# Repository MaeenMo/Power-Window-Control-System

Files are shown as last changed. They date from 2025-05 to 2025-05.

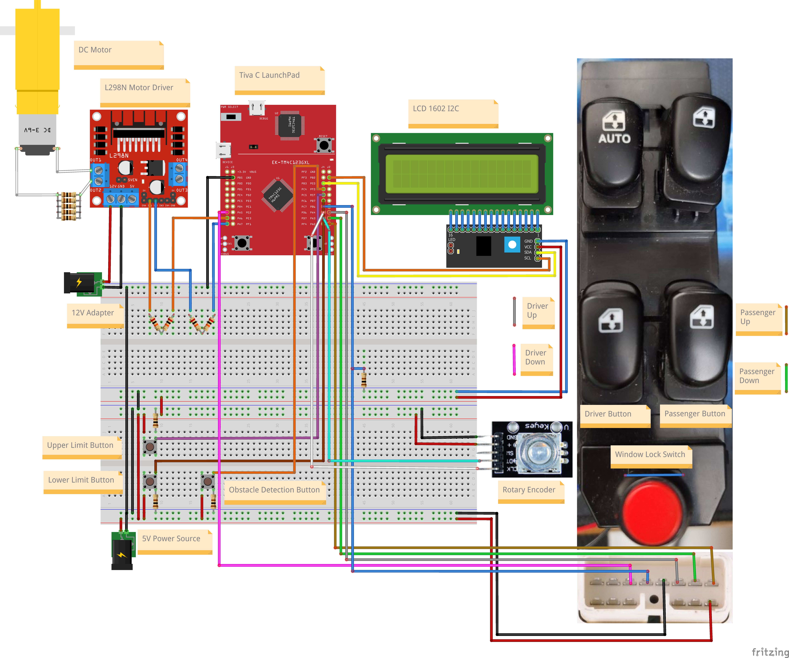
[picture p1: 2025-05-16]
Fritzing/Circuit Diagram.png

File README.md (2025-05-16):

# Power Window Control System

A real-time embedded system for controlling automotive power windows using the **TM4C123GH6PM** microcontroller and **FreeRTOS**.

---

## 🚗 Features

- **Dual Control:** Driver and passenger can operate the window independently.
- **Manual and Auto Modes:**
    - *Manual:* Window moves while the button is held.
    - *Auto:* One-touch open/close.
- **Safety Mechanisms:**
    - *Anti-pinch protection:* Automatically reverses window if obstacle is detected.
    - *Window lock:* Driver can disable passenger controls.
    - *Limit switch detection:* Prevents over-travel at top/bottom ends.
- **Encoder-Based Tracking:**
    - Real-time position tracking via rotary encoder.
    - Accurate calculation of open/close percentage.
- **User Feedback:**
    - LCD shows window state, lock status, and position percentage.
- **Debounced Inputs:** All switches are debounced using timers to ensure reliable signal handling.

---

## 🧰 Hardware Components

| Component | Description |
|---|---|
| TM4C123GH6PM MCU | Main controller |
| DC Motor + H-Bridge Driver | Controls window movement |
| Rotary Encoder (QEI) | Tracks window position |
| LCD (I2C) | Displays system status |
| Buttons (x4) | Driver/Passenger Up & Down |
| Limit Switches (x2) | Upper and lower travel limits |
| Lock Switch | Enables/disables passenger side |
| IR Obstacle Sensor (Simulated with a push-button) | Detects object in window path |

---

## 📍 Pin Configuration

### **Port A**
| Pin | Function |
|-----|---|
| PA2 | Passenger Up Button |
| PA3 | Passenger Down Button |
| PA4 | Driver Up Button |
| PA5 | Driver Down Button |
| PA6 | Motor IN1 (transistor base) |
| PA7 | Motor IN2 (transistor base) |

### **Port B**
| Pin | Function |
|-----|---|
| PB2 | I2C SCL |
| PB3 | I2C SDA |

### **Port C**
| Pin | Function |
|-----|---|
| PC4 | Object Detection Sensor |
| PC5 | Upper Limit Switch |
| PC6 | Lower Limit Switch |
| PC7 | Window Lock Switch |

### **Port D**
| Pin | Function |
|-----|---|
| PD6 | QEI Phase A |
| PD7 | QEI Phase B |

---

## 🧠 Software Architecture

### 🔧 Modules

- **Window Control Module:** Handles manual and auto control from driver and passenger sides.
- **Sensor & Safety Module:** Processes limit switches, lock switch, and obstacle detection.
- **Encoder Module:** Computes window position using rotary encoder and maps it to a 0–100% range.
- **LCD Module:** Displays real-time status (window state, lock icon, percentage open).
- **Configuration Module:** Initializes ports, system clock, and defines macros and pin assignments.

### 🧵 Tasks (FreeRTOS)

- `vDriverWindowElevateTask`
- `vDriverWindowLowerTask`
- `vPassengerWindowElevateTask`
- `vPassengerWindowLowerTask`
- `vLockWindowsTask`
- `vUpperLimitTask`
- `vLowerLimitTask`
- `vObstacleDetection`
- `vEncoderMonitorTask`
- `vStatusProducerTask`
- `vLCDTask`

---

## 🛡️ Safety Features

| Feature | Description |
|---|---|
| **Anti-Pinch** | IR sensor detects obstacles and reverses motor to prevent injury |
| **Window Lock** | Driver can lock/unlock passenger control |
| **Limit Protection**| Stops motor at top and bottom window positions |
| **Auto Mode Cancel**| Any button press cancels auto movement immediately |
| **Encoder Clamping**| Window position is clamped between 0–100% to prevent invalid states |

---

## ⚙️ Build & Flash Instructions

1. Open the project in **Keil uVision5**
2. Ensure **TivaWare** and **FreeRTOS** are properly linked.
3. Connect TM4C123GH6PM via **USB Debug Interface**.
4. Build the project (`Rebuild all`).
5. Flash to board (`Load` or `Ctrl + F8`).

---

## 📦 Dependencies

- [TivaWare Peripheral Driver Library](https://www.ti.com/tool/SW-TM4C)
- [FreeRTOS Kernel](https://freertos.org/)
- Keil MDK ARM IDE (or compatible)

---

## ✅ Future Improvements

- Add QEI direction filtering to discard noise.
- Add velocity monitoring for smoother motion.
- Enable EEPROM/Flash storage to retain calibration values.

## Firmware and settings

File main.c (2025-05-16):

#include "Config.h"
#include "Helper_Functions.h"
#include "WindowTasks.h"
#include "Safety.h"
#include "RotaryEncoder.h"
#include "LCD.h"

/* Global Variables */
#pragma clang diagnostic push
#pragma ide diagnostic ignored "EndlessLoop"

volatile bool debounce_in_progress = false; // variable for handling the debounce state

TimerHandle_t xDebounceTimer;

/*––– MAIN –––*/
int main(void) {
    // Clock
    SysCtlClockSet(
            SYSCTL_SYSDIV_5 | SYSCTL_USE_PLL | SYSCTL_OSC_MAIN | SYSCTL_XTAL_16MHZ
    );

    // Init I/O
    PortA_Config();         // must set PA6, PA7 outputs; PA4..2 inputs w/ digital enable
    PortB_Config_LCD();     // LCD sets PB2-SCL, PB3-SDA
    PortC_Config();         // limit switches, lock switch, IR sensor
    PortD_Config_QEI();     // QEI inputs (Encoder) PD6-CLK PD7-DT

    // LCD
    I2CMasterInitExpClk(I2C0_BASE, SysCtlClockGet(), false);
    LCD_I2C_Init();

    // --- create queue & tasks ---
    xStatusQueue = xQueueCreate(1, sizeof(StatusMsg_t));

    // Semaphores
    xDriverUpSem       = xSemaphoreCreateBinary();
    xDriverDownSem     = xSemaphoreCreateBinary();
    xPassengerUpSem    = xSemaphoreCreateBinary();
    xPassengerDownSem  = xSemaphoreCreateBinary();
    xLockWindowsSem    = xSemaphoreCreateBinary();
    xUpperLimitSem     = xSemaphoreCreateBinary();
    xLowerLimitSem     = xSemaphoreCreateBinary();
    xObstacleDetectionSem = xSemaphoreCreateBinary();

    // GPIO interrupts
    GPIOIntRegister(GPIO_PORTA_BASE, ISRHandlers);
    GPIOIntRegister(GPIO_PORTC_BASE, ISRHandlers);

    // Create single-touch driver‑up task
    xTaskCreate(vDriverWindowElevateTask, "DrvUp", 128, NULL, 3, &xDriverWindowElevateTaskHandle);
    xTaskCreate(vDriverWindowLowerTask, "DrvDn", 128, NULL, 3, &xDriverWindowLowerTaskHandle);
    xTaskCreate(vPassengerWindowElevateTask, "PUp", 128, NULL, 3, &xPassengerWindowElevateTaskHandle);
    xTaskCreate(vPassengerWindowLowerTask, "PDn", 128, NULL, 3, &xPassengerWindowLowerTaskHandle);
    xTaskCreate(vLockWindowsTask, "LockCtrl", 128, NULL, 4, &xLockWindowsTaskHandle);
    xTaskCreate(vUpperLimitTask, "UpperLimit", 128, NULL, 5, &xUpperLimitTaskHandle);
    xTaskCreate(vLowerLimitTask, "LowerLimit", 128, NULL, 5, &xLowerLimitTaskHandle);
    xTaskCreate(vObstacleDetection, "ObstacleDet", 128, NULL, 6, &xObstacleDetectionHandle);
    xTaskCreate(vLCDTask,            "LCD",   128, NULL, 2, NULL);
    xTaskCreate(vStatusProducerTask, "Stat",  128, NULL, 1, NULL);
    xTaskCreate(vEncoderMonitorTask,       "Enc",   128, NULL, 1, NULL);

    xDebounceTimer = xTimerCreate(
            "DebounceTimer",                // Timer name
            pdMS_TO_TICKS(350),             // Timer period
            pdFALSE,                        // One-shot timer
            (void*)0,                       // Timer ID
            vDebounceTimerCallback          // Callback function
    );

    // Start scheduler
    vTaskStartScheduler();

    while (1);
    // should never get here
}

/* Idle Task for sleeping the processor */
void vApplicationIdleHook( void ) {
    // Checking for initial condition of switch
    lock_state = GPIOPinRead(Sensors_Port,Window_Lock_Switch);
    // Disabling the passenger control
    if (lock_state == LOW){
        vTaskSuspend(xPassengerWindowElevateTaskHandle);
        vTaskSuspend(xPassengerWindowLowerTaskHandle);
    }
    /* Put the microcontroller in a low power mode */
    SysCtlSleep();
}

/*––– ISR HANDLER –––*/
void ISRHandlers(void) {
    BaseType_t xHigherPriorityTaskWoken = pdFALSE;

    // Read *all* pending (masked) interrupts on each port
    uint32_t a = GPIOIntStatus(GPIO_PORTA_BASE, true);
    uint32_t c = GPIOIntStatus(GPIO_PORTC_BASE, true);

    // If it's a button bounce, and we're still debouncing, clear PORTA and PORTC.
    if( debounce_in_progress && a )
    {
        GPIOIntClear(GPIO_PORTA_BASE, a);
        GPIOIntClear(GPIO_PORTC_BASE, c);
        return;
    }

    // If this is the first button edge, start the debounce timer
    if( a )
    {
        debounce_in_progress = true;
        xTimerStartFromISR(xDebounceTimer, &xHigherPriorityTaskWoken);
    }

    // — PORT A —
    if (a & Driver_Elevate_Button) {
        if(last_task == STOP){
            // Wake the driver‑up task
            xSemaphoreGiveFromISR(xDriverUpSem, &xHigherPriorityTaskWoken);
        }
    }
    else if (a & Driver_Lower_Button) {
        if (last_task == STOP) {
            // Wake the passenger‑up task
            xSemaphoreGiveFromISR(xDriverDownSem, &xHigherPriorityTaskWoken);
        }
    }
    else if (a & Passenger_Elevate_Button) {
        if (lock_state == HIGH && last_task == STOP) {
            // Wake the passenger‑up task
            xSemaphoreGiveFromISR(xPassengerUpSem, &xHigherPriorityTaskWoken);
        }
    }
    else if (a & Passenger_Lower_Button) {
        if (lock_state == HIGH && last_task == STOP) {
            // Wake the passenger‑down task
            xSemaphoreGiveFromISR(xPassengerDownSem, &xHigherPriorityTaskWoken);
        }
    }
    // — PORT C —
    else if (c & Window_Lock_Switch) {
        GPIOIntClear(GPIO_PORTC_BASE, Window_Lock_Switch);
        xSemaphoreGiveFromISR(xLockWindowsSem, &xHigherPriorityTaskWoken);
    }
    else if (c & Window_Upper_Limit) {
        GPIOIntClear(GPIO_PORTC_BASE, Window_Upper_Limit);

        uint8_t good = 0;
        for (uint8_t i = 0; i < 3; ++i) {
            if (GPIOPinRead(Sensors_Port, Window_Upper_Limit))
                good++;
            for (uint8_t i = 0; i < 10; ++i);
        }
        if (good == 0x3) {
            xSemaphoreGiveFromISR(xUpperLimitSem, &xHigherPriorityTaskWoken);
        }

    }
    else if (c & Window_Lower_Limit) {
        GPIOIntClear(GPIO_PORTC_BASE, Window_Lower_Limit);

        uint8_t good = 0;
        for (uint8_t i = 0; i < 3; ++i) {
            if (GPIOPinRead(Sensors_Port, Window_Lower_Limit))
                good++;
            for (uint8_t i = 0; i < 10; i++);
        }
        if (good == 0x3) {
            xSemaphoreGiveFromISR(xLowerLimitSem, &xHigherPriorityTaskWoken);
        }
    }
    else if (c & Object_Detection_Sensor) {
        GPIOIntClear(GPIO_PORTC_BASE, Object_Detection_Sensor);

        if (operation == UP) {
            uint8_t good = 0;
            for (uint8_t i = 0; i < 3; ++i) {
                if (GPIOPinRead(Sensors_Port, Object_Detection_Sensor))
                    good++;
                for (uint8_t i = 0; i < 10; ++i);
            }
            if (good == 0x3) {
                xSemaphoreGiveFromISR(xObstacleDetectionSem, &xHigherPriorityTaskWoken);
            }
        }
    }
    portYIELD_FROM_ISR(xHigherPriorityTaskWoken);
}

void vDebounceTimerCallback(TimerHandle_t xTimer) {
    debounce_in_progress = false;
}

#pragma clang diagnostic pop

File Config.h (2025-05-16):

#ifndef __PORT_Configuration__
#define __PORT_Configuration__ 

#include <stdint.h>
#include <stdbool.h>
#include <stdio.h>

#include "FreeRTOS.h"
#include "task.h"
#include "queue.h"
#include "semphr.h"
#include "timers.h"

#include "inc/hw_memmap.h"
#include "inc/hw_types.h"
#include "inc/hw_ints.h"

#include "driverlib/sysctl.h"
#include "driverlib/gpio.h"
#include "driverlib/pin_map.h"
#include "driverlib/interrupt.h"
#include "driverlib/i2c.h"
#include "driverlib/qei.h"

#include "lcd_i2c.h"

#include "TM4C123GH6PM.h"
#define SYSCTL_RCGCGPIO_R       (*((volatile unsigned long *)0x400FE608))

/* PORTA Registers */
#define GPIO_PORTA_DATA_BITS_R  ((volatile uint32_t *)0x40004000)
#define GPIO_PORTA_DATA_R       (*((volatile uint32_t *)0x400043FC))
#define GPIO_PORTA_DIR_R        (*((volatile uint32_t *)0x40004400))
#define GPIO_PORTA_IS_R         (*((volatile uint32_t *)0x40004404))
#define GPIO_PORTA_IBE_R        (*((volatile uint32_t *)0x40004408))
#define GPIO_PORTA_IEV_R        (*((volatile uint32_t *)0x4000440C))
#define GPIO_PORTA_IM_R         (*((volatile uint32_t *)0x40004410))
#define GPIO_PORTA_RIS_R        (*((volatile uint32_t *)0x40004414))
#define GPIO_PORTA_MIS_R        (*((volatile uint32_t *)0x40004418))
#define GPIO_PORTA_ICR_R        (*((volatile uint32_t *)0x4000441C))
#define GPIO_PORTA_AFSEL_R      (*((volatile uint32_t *)0x40004420))
#define GPIO_PORTA_DR2R_R       (*((volatile uint32_t *)0x40004500))
#define GPIO_PORTA_DR4R_R       (*((volatile uint32_t *)0x40004504))
#define GPIO_PORTA_DR8R_R       (*((volatile uint32_t *)0x40004508))
#define GPIO_PORTA_ODR_R        (*((volatile uint32_t *)0x4000450C))
#define GPIO_PORTA_PUR_R        (*((volatile uint32_t *)0x40004510))
#define GPIO_PORTA_PDR_R        (*((volatile uint32_t *)0x40004514))
#define GPIO_PORTA_SLR_R        (*((volatile uint32_t *)0x40004518))
#define GPIO_PORTA_DEN_R        (*((volatile uint32_t *)0x4000451C))
#define GPIO_PORTA_LOCK_R       (*((volatile uint32_t *)0x40004520))
#define GPIO_PORTA_CR_R         (*((volatile uint32_t *)0x40004524))
#define GPIO_PORTA_AMSEL_R      (*((volatile uint32_t *)0x40004528))
#define GPIO_PORTA_PCTL_R       (*((volatile uint32_t *)0x4000452C))
#define GPIO_PORTA_ADCCTL_R     (*((volatile uint32_t *)0x40004530))
#define GPIO_PORTA_DMACTL_R     (*((volatile uint32_t *)0x40004534))
	
/* PORTB Registers */
#define GPIO_PORTB_DATA_BITS_R  ((volatile uint32_t *)0x40005000)
#define GPIO_PORTB_DATA_R       (*((volatile uint32_t *)0x400053FC))
#define GPIO_PORTB_DIR_R        (*((volatile uint32_t *)0x40005400))
#define GPIO_PORTB_IS_R         (*((volatile uint32_t *)0x40005404))
#define GPIO_PORTB_IBE_R        (*((volatile uint32_t *)0x40005408))
#define GPIO_PORTB_IEV_R        (*((volatile uint32_t *)0x4000540C))
#define GPIO_PORTB_IM_R         (*((volatile uint32_t *)0x40005410))
#define GPIO_PORTB_RIS_R        (*((volatile uint32_t *)0x40005414))
#define GPIO_PORTB_MIS_R        (*((volatile uint32_t *)0x40005418))
#define GPIO_PORTB_ICR_R        (*((volatile uint32_t *)0x4000541C))
#define GPIO_PORTB_AFSEL_R      (*((volatile uint32_t *)0x40005420))
#define GPIO_PORTB_DR2R_R       (*((volatile uint32_t *)0x40005500))
#define GPIO_PORTB_DR4R_R       (*((volatile uint32_t *)0x40005504))
#define GPIO_PORTB_DR8R_R       (*((volatile uint32_t *)0x40005508))
#define GPIO_PORTB_ODR_R        (*((volatile uint32_t *)0x4000550C))
#define GPIO_PORTB_PUR_R        (*((volatile uint32_t *)0x40005510))
#define GPIO_PORTB_PDR_R        (*((volatile uint32_t *)0x40005514))
#define GPIO_PORTB_SLR_R        (*((volatile uint32_t *)0x40005518))
#define GPIO_PORTB_DEN_R        (*((volatile uint32_t *)0x4000551C))
#define GPIO_PORTB_LOCK_R       (*((volatile uint32_t *)0x40005520))
#define GPIO_PORTB_CR_R         (*((volatile uint32_t *)0x40005524))
#define GPIO_PORTB_AMSEL_R      (*((volatile uint32_t *)0x40005528))
#define GPIO_PORTB_PCTL_R       (*((volatile uint32_t *)0x4000552C))
#define GPIO_PORTB_ADCCTL_R     (*((volatile uint32_t *)0x40005530))
#define GPIO_PORTB_DMACTL_R     (*((volatile uint32_t *)0x40005534))
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

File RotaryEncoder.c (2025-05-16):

#include "RotaryEncoder.h"

volatile uint32_t TOTAL_PULSES = 150UL;   // pulses from top→bottom
volatile uint32_t windowPct      = 0;        // 0–100%


/*––– ENCODER MONITOR –––*/
void vEncoderMonitorTask(void *pv) {
    QEIPositionSet(QEI0_BASE, 0);
    while (1) {
        int8_t dir = QEIDirectionGet(QEI0_BASE);  // +1 = CW, -1 = CCW

        if (operation == UP && dir > 0) {
            // Closing: percentage increases
            uint32_t speed = QEIVelocityGet(QEI0_BASE);
            if (speed < 16) {
                QEIPositionSet(QEI0_BASE, prev_pos); // ignore as noise
                continue;
            }
            handle_position_bounds(&pos);
            if (pos > prev_pos) {
                windowPct = (pos * 100UL / TOTAL_PULSES);
                prev_pos = pos;
            }
            else QEIPositionSet(QEI0_BASE, prev_pos);
            if (windowPct > 100) windowPct = 100;
            if (windowPct == 100){
                prev_pos = TOTAL_PULSES;
                trigger_limit_semaphore(xUpperLimitSem, &encoder_limit);
            }
        } else if (operation == DOWN && dir < 0) {
            // Opening: percentage decreases
            uint32_t speed = QEIVelocityGet(QEI0_BASE);
            if (speed < 16) {
                QEIPositionSet(QEI0_BASE, prev_pos); // ignore as noise
                continue;
            }
            handle_position_bounds(&pos);
            if (pos < prev_pos) {
                windowPct = (pos * 100UL) / TOTAL_PULSES;
                prev_pos = pos;
            }
            else QEIPositionSet(QEI0_BASE, prev_pos);
            if (windowPct < 0) windowPct = 0;
            if (windowPct > 100) windowPct = 100;
            if (windowPct == 0){
                prev_pos = 0;
                trigger_limit_semaphore(xLowerLimitSem, &encoder_limit);
            }
        } else if (operation == STOP){
            QEIPositionSet(QEI0_BASE, pos); // Set the position to the last known value
        }
        vTaskDelay(pdMS_TO_TICKS(100));
    }
}

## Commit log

2025-04-21 add: Driver/Passenger button functionality
2025-04-21 add: DebouncerTimer to fix button debounce issue
    [main.c]
2025-04-24 add: Lock window switch functionality, fix: added initial semaphores take functions to block tasks for first time
    [main.c]
2025-04-27 add: Upper/Lower limits Tasks, fix: lock check in idle hook disabled motor for driver also, remove: debounce temporary
    [main.c]
2025-04-29 add: lcd task and monitor task, fix: debounce delay with new isr handler logic
    [Port_Config.c, Port_Config.h, main.c]
2025-04-29 edit: lock_state to match the new window control lock switch, fix: lcd winstat was inverted
    [main.c]
2025-05-04 refactor: optimize motor control logic for one-touch auto mode
2025-05-05 refactor: reorganize project structure and enhance GPIO interrupt handling, added obstacleDetection task
2025-05-11 feat: update window control logic with auto mode. added: obstacle detection features. fixed: encoder functions
    [Config.h, Helper_Functions.c, Port_Config.c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]
2025-05-14 refactor: update data types for task and state variables, enhance encoder handling and limit switch logic
2025-05-15 refactor: adjust TOTAL_PULSES for window control, improve debounce handling, enhance obstacle detection logic, and limit switch ISRs
2025-05-15 refactor: reorganize project structure, add new source files for rotary encoder, window tasks, safety, and LCD handling
2025-05-16 add: Circuit Diagram by fritzing
    [Circuit Diagram.fzz]
2025-05-16 refactor: update function signatures and added comments
    [Circuit Diagram.fzz]
2025-05-16 refactor: update vDebounceTimerCallback signature and improve rotary encoder noise handling
    [Config.h, Helper_Functions.c, Port_Config.c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]
